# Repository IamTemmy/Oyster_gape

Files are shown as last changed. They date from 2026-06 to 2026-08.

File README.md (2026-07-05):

# Oyster_gape

Non-contact measurement of oyster valve **gape** (how far the shells open and
close) using a Micronas **HAL 2425** Hall-effect sensor on one shell and a small
magnet on the other. As the gap changes, the sensor output changes. This repo
covers the sensor engineering: characterizing and **linearizing** the HAL 2425 so
its output reads linearly in millimetres, then a **three-sensor bench system**
(Board B) that shows live gape on a web dashboard, with a **per-unit tare** so
each unit reports true gape from its own closed baseline.

This is a clean restart. Nothing here is inherited unverified from prior work —
every constant is measured and documented.

---

## Demo

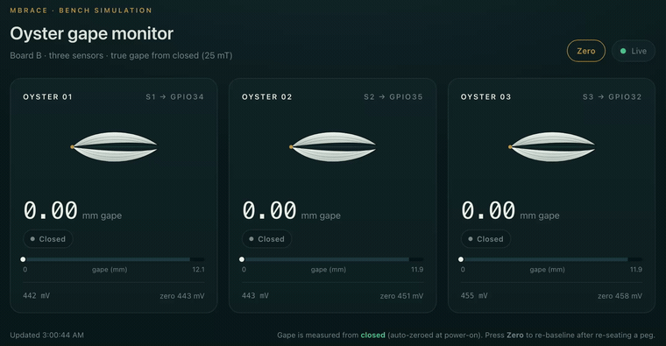
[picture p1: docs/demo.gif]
Oyster gape dashboard demo


Three clothespin "oysters" on Board B's live dashboard — each shell opens in
proportion to the measured gape. Closed reads 0.00 mm (per-unit tare); the
slightest press registers immediately.
**[Watch the full video →](https://github.com/IamTemmy/Oyster_gape/releases/tag/v0.1-bench-demo)**
· more in [`docs/demo.md`](docs/demo.md).

---

## Current stage

**Bench system working — 25 mT + tare (Board B).** The full method is proven on
three clothespin "oysters" (pegs standing in for real animals):

- Sensors characterized and **linearized** (Micronas workflow, Procedure 03),
  first at 12 mT then re-done at **25 mT** (window 8.0–20.0) so the closed peg sits
  on the active ramp instead of in the dead zone.
- **Board B** (ESP32-WROVER) reads all three sensors (S1/S2/S3 → GPIO34/35/32, all
  ADC1) and serves a live **web dashboard** (`firmware/06_board_b_tare`).
- **Per-unit tare:** each unit records its own closed reading as a baseline and
  reports **true gape from closed** — `gape = (mV − baseline) / m`. The intercept
  cancels in that subtraction, so the per-unit mounting offset drops out. This is
  what lets one lab calibration serve many differently-mounted animals.

Per-sensor lines and the full method:
[`data/analysis/deployment_calibration.md`](data/analysis/deployment_calibration.md).
Watch it work: [demo](docs/demo.md).

**Next (deployment):** re-run the same method at the range chosen for real oysters
(see decisions log), add a mounting jig for consistent closed standoff, and
flash-persist the baselines so a tare survives power cycles.

---

## Hardware facts (current rig)

| Item | Value |
|---|---|
| Sensor | Micronas HAL 2425 (16 linearization setpoints) |
| Programmer / software | HAL-APB on COM-port, HAL/HAR 24xy Programming Environment (SW v3.04) |
| Controller | ESP32-WROVER (Freenove) |
| Driver | Geckodrive G251 — **fixed 10 microsteps/full step → 2000 pulses/rev** |
| Motor | 200 full-step |
| Magnet | 3/8" dia × 1/8" thick, N40 neodymium, axially magnetized |

### Pin map

| Signal | ESP32 | Notes |
|---|---|---|
| STEP | GPIO18 | → G251 Terminal 10 |
| DIR  | GPIO19 | → G251 Terminal 9 |
| Sensor analog in | GPIO34 | ADC1_CH6, input-only. **Not** GPIO4 (that is ADC2, WiFi-conflicting) |
| Common ground | GND | shared with G251 Terminal 12 |

### Analog front end (sensor output → ESP32) — DECIDED: ÷1.5, no cap

- **Divider: ÷1.5** (two 10 kΩ in parallel = 5 kΩ on top, one 10 kΩ to ground).
  The Stage 02 2×2 test showed ÷1.5 and ÷2 back-scale to the same true curve
  within 0.3% — ÷1.5 does **not** clip with this magnet/geometry — while ÷1.5
  spans ~1.33× more mV at the pin, giving more ADC resolution. (Re-check if a
  future geometry brings the magnet much closer and raises the output.)
- **No filter cap.** No-cap noise is ~6 mV SD → ~0.45 mV after 200-sample
  averaging — already excellent. On this ÷1.5 setup the cap **reproducibly
  raised** noise (~21 mV SD, confirmed on a clean retest — not a loose
  connection). Cause not pinned down (likely the specific cap interacting with
  the breadboard/ADC), but irrelevant: the cap isn't needed and hurts here, so
  it's dropped. See data/analysis/.
- Decouple the sensor's 5 V supply with 100 nF + ~4.7 µF at its pins
  (output is ratiometric, so supply ripple = error).

---

## Key decisions log

- **Noise:** keep the ESP32 (per advisor); attack noise in firmware via
  oversampling + averaging + settle time, on ADC1. External ADC (e.g. ADS1115)
  held as a fallback only.
- **Analog front end:** **÷1.5 divider, no cap** (Stage 02 2×2 test). ÷1.5
  proven not to clip (back-scales to ÷2 within 0.3%) and gives more resolution;
  cap unneeded because 200-sample averaging drives noise to ~0.5 mV.
- **Magnetic range:** ±3 mT is **blind below ~12 mm** with this magnet (near field
  clips); higher ranges reach smaller gaps. **Bench: ±25 mT** — chosen and
  bench-proven (window 8.0–20.0) because it places the peg's closed gap on the ramp
  without pushing the window start into the steep shoulder (the F:000000 spike).
  **Deployment: likely ±3 mT** for real (larger) oysters — the professor's lean,
  for its longer operating range at larger separations. The *method* is
  range-independent (linearize → mount so closed is on-ramp → tare), so deployment
  re-runs it at the final range once the oyster geometry is known.
  *(Updated 2026-07-05; earlier this read "final choice pending the measured gape window.")*
- **Distance constant:** measured = **0.001 mm/pulse** (1000 pulses/mm,
  2.0 mm/rev), Procedure 01.
- **Output polarity:** sensor output **falls** with increasing gap
  (closed = high mV ~3.6 V, open = low mV). Kept on purpose: it places the
  closed→just-opening transition in the high-signal, high-resolution region —
  the event the research most cares about. A falling curve linearizes exactly
  like a rising one. Deployment caveat: "fully open" and "unpowered / broken
  wire" both read low — rely on the HAL's wire-break detection to disambiguate.
- **Per-sensor calibration:** every sensor is characterized and linearized
  **individually** — setpoint files are NOT shareable between units (intrinsic
  part spread + mounting variation from bent pins + magnet pairing). The process
  is identical each time and the high-level settings (range, output mapping) are
  shared; only the sweep + setpoints + a per-unit 2-point calibration are
  repeated. The 2-point cal is what absorbs mounting-distance variation. A sensor
  must be characterized in (or in a jig replicating) its final mounting geometry.
  Future shortcut to validate empirically: if several sensors' curve *shapes*
  match, share one curve + per-unit 2-point cal only.
- **LOCK is irreversible.** Locking a sensor can never be undone — every
  programming session ends with an explicit LOCK checklist before that button.

---

## Conventions

- One firmware sketch per folder (Arduino requirement), numbered by stage.
- Every stage has a matching `docs/procedures/NN_*.md` with a results table
  filled in from the real run.
- Raw data lands in `data/` with the sketch/run that produced it named in the file.

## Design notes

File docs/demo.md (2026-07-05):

# Demo — bench simulation (25 mT + tare)

Oyster gape dashboard demo

*Board B's live dashboard. Three clothespin "oysters," each with a HAL 2425 sensor
and a magnet on opposing jaws — the clothespin mouth is the shell gape. Each shell
on screen opens in proportion to the measured gape.*

## What the clip shows

- All three start **closed at 0.00 mm** ("Closed").
- Each peg is pressed open — the shell splays and the gape reads live in mm.
- Released back to closed → returns to **0.00 mm**. The per-unit **tare** holds the
  closed baseline, so closed is a true zero, not a fixed guess.

## Setup

- Firmware: [`firmware/06_board_b_tare`](../firmware/06_board_b_tare) on an ESP32-WROVER (Board B).
- Sensors S1/S2/S3 → GPIO34 / GPIO35 / GPIO32 (all ADC1, ÷1.5 front end).
- Linearized at **25 mT**, window **8.0–20.0** (see
  [`data/analysis/deployment_calibration.md`](../data/analysis/deployment_calibration.md)).
- **Per-unit tare:** `gape = (mV − baseline) / m`; the intercept cancels, so each unit
  reports true gape from its own closed baseline — the mechanism that generalizes across
  differently-mounted units.
- Dashboard gauge **auto-scales** to each unit's physical opening range.

## Full video

▶ **[Watch the full demo — Release v0.1-bench-demo](https://github.com/IamTemmy/Oyster_gape/releases/tag/v0.1-bench-demo)**

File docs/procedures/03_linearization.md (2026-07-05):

# Procedure 03 — Per-Range Linearization

**Goal:** for each magnetic range, straighten the sensor's output so it reads
proportional to gap, using the HAL 2425's 16 setpoints, and verify it.

**Sketch:** `firmware/03_linearization/03_linearization.ino` (modes: `cal`, `lin`, `verify`)
**Logger:** `host/sweep_logger.py` (captures the `verify` sweep)

This is the same procedure for all eight ranges — only the **window** changes.

---

## Windows (START / END per range) — verified

These are the **corrected, verified** windows — the value you type: `window START END`.
Each START was pushed past that range's steep shoulder; the initial guesses were too
low and made the linearizer's inverse spike (F:000000, unwritable). Full narrative in
`data/analysis/linearization_log.md`.

| Range | START (mm) | END (mm) | Status |
|---|---|---|---|
| 100 mT | 4.0 | 14.0 | verified (2.6%) |
| 50 mT | 6.0 | 16.0 | verified (1.4%, cleanest) |
| 25 mT | 8.0 | 20.0 | verified (2.0%) — bench build |
| 12 mT | 11.0 | 24.0 | verified (2.3%) |
| 6 mT | 17.0 | 32.0 | verified (2.6%) |
| 3 mT | 20.0 | 38.0 | verified (3.1%) |
| 200 mT | — | — | **IMPRACTICAL** — swing vs gentle-start squeeze |
| 400 mT | — | — | **IMPRACTICAL** — swing too small to calibrate |

START sits just past each range's steep shoulder (further out as sensitivity rises —
a clipped/flat or too-steep span can't be linearized); END sits before the flat tail.
The table gives the **window command**; the *measured* ramp runs a little wider (e.g.
25 mT command 8.0–20.0 → measured ramp ~8.5–20.7, see the range ladder in
`linearization_log.md`). **200 mT and 400 mT do not linearize with this magnet**, so
start the campaign at **100 mT** and work down the table.

## Settings (same for every range)

- **OUT_MIN / OUT_MAX = 10% / 90%** — keeps the signal inside the sensor's
  full-accuracy band (~7–93% VSUP) and leaves headroom for wire-break/clamp
  diagnostics. Don't use 0/100.
- **SCALE_MIN / SCALE_MAX = 1024 / 29696** (the tool defaults) — uses most of
  the internal 0–32767 range.

## Connections — which device owns the OUT line

- **cal / lin:** the **Micronas programmer reads the sensor** → programmer
  connected. (The ESP32 only drives the motor here; it does not read OUT.)
- **verify:** the **ESP32 reads the analog output** → **disconnect the
  programmer** from the OUT line first (the "lines flying" problem).
- STEP/DIR (motor) stay connected the whole time.
- If Micronas comms glitch during cal/lin, also lift the ÷1.5 divider off OUT so
  only the programmer is on it.

---

## Per-range loop

1. **Reset + range** (Sensor Settings): Set Default Values → Magnetic Range =
   target → Write Customer Setup → Power On Reset. (Clears any prior
   linearization so ranges don't stack.)
2. **Set the window in the sketch:** rest the carriage gently on the block →
   `zero` → `window <START> <END>` for this range.
3. **2-Point Calibration** (Micronas tool): enter SCALE_MIN/MAX defaults and
   OUT_MIN/MAX = 10/90 → in the sketch run **`cal`**:
   - it goes to START → click **Calibration Point 1** → press ENTER
   - it goes to END → click **Calibration Point 2** → press ENTER
   - then **Calculate Signal Path** → **Write Signal Path**.
4. **16-point measurement** (Measurement Tool open): in the sketch run **`lin`**:
   - at each of the 16 stops, wait until the magnet has **stopped moving**, click
     **Yes** on the tool's "position reached?" prompt, then press ENTER to advance.
   - when done, the tool **saves the setpoint file** itself.
5. **Linearize + write setpoints** (Linearization Tool): Load Meas. File →
   **Linearize with Extrapolation UNCHECKED** (clamps the output outside the window)
   → **inspect the green Transfer Curve before writing** — a smooth bow is good, a
   small kink is usually fine, but a **big spike (hundreds–thousands of %FS) means DO
   NOT write**: the write fails with `error during programming F:000000`. That spike
   means the window START sits on the curve's steep shoulder — move START further out
   and redo from step 2. When the green curve is clean → **Write Setpoints**.
6. **Verify:** disconnect the programmer from OUT. In the logger set
   `:range <range>mT_linearized`, then in the sketch run **`verify`**. The logger
   saves `charac_<range>mT_linearized_run1.csv` + `.png`.

**The green Transfer Curve is the go/no-go; the `verify` sweep is the final arbiter.**

**A good verify looks like:** flat clamp (10%) → straight diagonal ramp across
the window → flat clamp (90%). The straight ramp is the proof. Overlay it on the
raw `charac_<range>mT` curve for the before/after figure.

---

## Sketch command reference

```
zero              set datum at current position (do this on the block)
window <a> <b>    set window, e.g.  window 1.0 10.0
cal               visit START then END (ENTER to advance, q to abort)
lin               walk 16 even stops START->END (ENTER each, q to abort)
verify            100 mm sweep, streamed to the logger
<integer>         jog pulses (1000 = 1 mm, + = away from sensor)
pos / help
```

One command at a time; wait for each reply (avoids the merged-line problem).

## Records to keep per range

Sensor ID/channel, range, window START/END, OUT_MIN/MAX, the saved setpoint
file, and the `verify` CSV/PNG. These are the per-unit calibration identity.

## Notes

- Output falls with gap (our polarity), so the linearized ramp will also be a
  clean monotonic line — direction doesn't matter to the linearizer.
- `cal`, `lin`, `verify` all return to the datum (block) when finished, so you
  don't reposition between steps. Re-`zero` on the block if you suspect drift.

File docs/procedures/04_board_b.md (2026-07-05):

# Procedure 04 — Board B: live readout, dashboard, and tare

**Goal:** read the linearized sensors on a second ESP32 (Board B) and report
**true gape** — the shell opening from closed — on a serial readout and a live web
dashboard.

**Sketches (Board B, one folder each):**
- `firmware/04_board_b_readout/` — 3-sensor serial readout (bench debug)
- `firmware/05_board_b_dashboard/` — WiFi web dashboard (absolute mm)
- `firmware/06_board_b_tare/` — **current**: 25 mT + tare, reports true gape

**Calibration source:** `data/analysis/deployment_calibration.md` (per-sensor `m`,
`b`, ramp, clamp floors).

---

## Hardware (Board B — no motor)

| Signal | ESP32 | Notes |
|---|---|---|
| S1 in | GPIO34 | ADC1_CH6 |
| S2 in | GPIO35 | ADC1_CH7 |
| S3 in | GPIO32 | ADC1_CH4 |

- **All three on ADC1.** ADC2 shares hardware with the WiFi radio, so ADC2 reads
  fail once the dashboard's WiFi is up. ADC1 always works.
- One **÷1.5 divider per sensor** (2×10 kΩ parallel on signal + 1×10 kΩ to GND);
  do not share divider legs. Same front end as the rig.
- USB-powered (Phase 1). Battery/power is Phase 2 — deliberately not built in.

## Which sketch to flash

- **06 is the current build** — flash it for the demo and for true-gape readings.
- 04 (serial only) and 05 (dashboard, absolute mm) are kept as references / bench
  debug; 06 supersedes both.

## WiFi (05 / 06)

- Credentials + mode live in `secrets.h` (**gitignored**). Copy
  `secrets.example.h` → `secrets.h` in the sketch folder and fill it in.
- `NET_MODE`: `NET_AP` (Board B makes its own network → `http://192.168.4.1`) or
  `NET_STA` (join existing WiFi → IP printed on serial at boot). AP is the more
  reliable demo path; some institutional networks isolate clients and block the
  laptop from reaching Board B even when both are "connected."

---

## Before tare — the two gate checks

The tare only works if closed sits **on the ramp**. After mounting, read the raw
mV (serial `read`, or the dashboard footer) and confirm both:

1. **Closed peg on the ramp** — a mid-ramp mV, not the ~300 mV floor (CLAMP-LO).
2. **A realistic full-open still on the ramp** — under the ~3130 mV ceiling, not
   CLAMP-HI / "above window".

If closed clamps low, the window is too high for this mounting → re-linearize lower
(Procedure 03) or increase the mounting standoff. If full-open clamps high, the
opening range exceeds the window → widen it or drop to a lower range. (For the 25 mT
peg build these both passed: closed ~450 mV / ~8.5 mm, full-open ~2510 mV / ~17.9 mm.)

## Tare workflow (06)

    gape = (mV − baseline) / m

The intercept `b` cancels in that subtraction, so the per-unit mounting offset drops
out — every unit zeroes to itself and reads 0.00 mm closed.

- **Auto-capture at boot:** ~1.5 s after power-on the firmware captures each
  sensor's closed reading as its baseline. **Hold the pegs CLOSED through boot.**
- **On-ramp gate:** an off-ramp / clamped reading is **refused**, not zeroed to
  junk (shows "No baseline"). Close the peg and re-zero.
- **Re-baseline anytime:** serial `zero`, or the dashboard **Zero** button — needed
  after re-seating a peg or separating the magnet/sensor halves.
- **"Closed" band:** within ±0.05 mm of baseline reads as closed (≈ the noise
  floor), so closed holds steady; any real press registers immediately.
- **Gauge auto-scales** to each unit's physical max opening (`rampHi − baseline`) —
  no fixed full-scale constant.

---

## Sketch command reference (serial, 115200)

```
zero    re-capture the closed baseline (hold pegs closed first)   [06]
read    one-shot verbose read — absolute mm + gape                [04 / 06]
help    menu
```

The live readout is the web dashboard; serial is for setup / debug.

## Records to keep

Per unit: sensor ID → channel, the 25 mT `(m, b)` line used, the closed baseline mV
captured at install, and a caliper spot-check of gape at one open position.

## Notes

- Baselines live in RAM (re-captured each boot / on `zero`). **Deployment TODO:**
  persist to flash so a tare survives a power cycle.
- The tare removes **offset**, not **slope** — the magnet used at linearization must
  match the deployed magnet, or gape is scaled wrong.
- Hinge-arc error (the peg/oyster opens on an arc, not the rig's straight line) is
  taken as **minimal** per the professor; the tare does not correct it. Revisit if an
  animal opens much wider. See `data/analysis/deployment_calibration.md`.

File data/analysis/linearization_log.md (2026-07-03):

# Stage 03 — Linearization results log (per range)

Magnet: 3/8" x 1/8" N40 (fixed). Front end: ÷1.5, no cap. OUT_MIN/MAX = 10/90.

| Range | Window (mm) | Cal pt1 | Cal pt2 | Result |
|---|---|---|---|---|
| 400 mT | 1.0–10.0 | 3004 | 408 | REJECTED — "small range between calibration points" |
| 400 mT | 0.5–25.0 | 3444 | 64 | REJECTED — swing too small even widened. **400 mT not linearizable with this magnet.** |

## Notes
- 400 mT is the least sensitive range; its internal signal swing over the usable
  span is too small for the 2-point calibration to anchor. The tool itself flags
  it and suggests lowering the magnetic range — consistent with the Stage 02
  sensitivity analysis (400 mT had the smallest swing of all eight).
- Expectation: 200 mT likely the same; the sensitive ranges (50 mT and down) are
  the real candidates.

| 200 mT | 1.0–10.0 | 5940 | 808 | Calibrated OK, but linearization transfer spiked (>1000% FS) — unwritable (F:000000). |
| 200 mT | 4.0–14.0 | 2704 | 456 | REJECTED — pushing start out to tame the spike drops swing below calibration minimum. |
| 100 mT | 1.0–10.0 | 11932 | 1660 | Calibrated OK, but transfer spiked (~700% FS) — unwritable. Retesting with pushed-out start. |

## Finding (400 + 200 mT)
The two least-sensitive *non-clipping* ranges fail to linearize with this magnet,
for two linked reasons:
- **Swing too small** for the 2-point calibration (400 mT outright; 200 mT once
  the window is pushed out).
- **Steep first segment** (curve is steepest right at the block on non-clipping
  ranges) makes the linearizer's inverse spike (>1000% FS) → setpoints unwritable.
There is no window that gives both enough swing AND a gentle-enough start.
=> 400 mT and 200 mT are documented as IMPRACTICAL with the current magnet.
Next: confirm whether 100 mT (more swing) escapes the squeeze with a pushed-out start.

| 100 mT | 4.0–14.0 | 5404 | 916 | **SUCCESS** — smooth transfer, written, verified. Ramp straight to 2.6% (max 75 mV dev on 2900 mV ramp), slope ~260 mV/mm. |

## Method confirmed
The fix for non-clipping ranges: **start the window past the steep first segment**
(4 mm for 100 mT). 1 mm spiked (unwritable); 4 mm gave a clean flat–ramp–flat
verified at 2.6% linearity. 100 mT is the first fully linearized + verified range.

| 50 mT | 3.0–13.0 | 13636 | 2076 | Transfer spiked — start still too steep. |
| 50 mT | 6.0–16.0 | (recal) | | **SUCCESS** — smooth transfer, written, verified. Ramp straight to **1.4%** (max 39 mV dev), slope 258 mV/mm. Cleanest range so far; front-runner. |

## Linearization-safe window starts (corrected, per range)
Each range needs its window START pushed past its steep shoulder (further out as
sensitivity rises), or the linearizer's inverse spikes and setpoints won't write:
- 100 mT -> start 4.0 mm  (verified, 2.6%)
- 50 mT  -> start 6.0 mm  (verified, 1.4%)
- 25 mT  -> testing ~8.0 mm
(200/400 mT impractical: can't get swing + gentle start simultaneously.)

| 25 mT | 8.0–20.0 | (ok) | | **SUCCESS** — verified, ramp straight to 2.0%, slope 217 mV/mm, 8.5–20.7 mm. Wider window than 50mT. |

| 12 mT | 11.0–24.0 | (ok) | | **SUCCESS** — verified, see straightness in session. Window 11–26 mm. |

| 6 mT | 17.0–32.0 | (ok) | | **SUCCESS** — verified. Window 17–37 mm; widest span yet before 3mT. |

| 3 mT | 20.0–44.0 | (ok) | | First try bent at top (5.8%) — END reached the flat zone. Re-run accepted at 3.1%. |

---

# STAGE 03 — FINAL RESULTS (6 ranges linearized + verified)

| Range | Window start→end (mm) | Width (mm) | Slope (mV/mm) | Linearity (max dev) |
|---:|:---:|:---:|:---:|:---:|
| 3 mT | 21.8–43.7 | 21.9 | 115 | 3.1% |
| 6 mT | 18.2–36.4 | 18.2 | 140 | 2.6% |
| 12 mT  | 11.4–25.2 | 13.8 | 187 | 2.3% |
| 25 mT  | 8.5–20.7  | 12.2 | 217 | 2.0% |
| 50 mT  | 6.4–16.4  | 10.0 | 258 | 1.4% (cleanest) |
| 100 mT | 4.1–14.2  | 10.1 | 260 | 2.6% |
| 200 mT | — | — | — | IMPRACTICAL (swing vs gentle-start squeeze) |
| 400 mT | — | — | — | IMPRACTICAL (swing too small to calibrate) |

## Key findings
1. **Six usable linearized ranges (3–100 mT)**, each a straight gap-vs-output
   ramp, all within 1.4–3.1% linearity. Together they form a "range ladder":
   pick the range whose ramp covers a given oyster's gape window.
2. **Window rule:** each range's window must START past its steep shoulder
   (further out as the range gets more sensitive) and END before its flat tail —
   else the linearizer's inverse spikes (unwritable) or the ramp bends.
3. **Magnet reach limit ≈ 38 mm.** Going to the most sensitive range (3 mT) did
   NOT extend usable reach much beyond 6 mT — the field flattens by ~38 mm
   regardless of range. The largest gapes would need a stronger magnet.
4. **200/400 mT impractical** with this magnet: too little signal swing to both
   calibrate and linearize.
5. Measurement quality: more-sensitive ranges trade slope (resolution) for reach.
   50 mT is the cleanest/highest-resolution general-purpose choice.

## Open / next
- Deployment: pick range per oyster from its actual gape window (closed+open mm).
- Set Clamp-Low/High band + wire-break detection (currently 0/100).

---

# Experiment: magnetic range acts UPSTREAM of the signal path (CFX evidence)

**Question (raised by colleague):** can the stored signal path be tweaked to move a
range's ramp along the *distance* axis — e.g., make 3 mT read near the block like
100 mT does?

**Method:** magnet held FIXED at distance 0 (closest to block). Changed ONLY the
Magnetic Range dropdown; clicked Read All Registers each time. No recalibration,
no Load Signal Path.

**Observation (same magnet, same position):**

| Range  | CFX (raw sensed) | OUT[%FS] | Signal-path registers |
|---:|:---:|:---:|:---:|
| 100 mT | 16887 (~half scale) | 7.14 | unchanged |
| 50 mT  | 32767 (RAILED) | 7.14 | unchanged |
| 3 mT | 32767 (RAILED) | 7.14 | unchanged |

- Signal-path coefficients (TCCG / SCALE / OUT / clamps) did NOT change with range.
- Only RAM (live pipeline) values changed. **CFX is the tell.**

**Conclusion:**
- Magnetic range sets front-end sensitivity BEFORE the signal path. At a fixed
  strong-field position the sensitive ranges (3/50 mT) rail the raw sensed value
  (CFX = 32767 = full scale); the insensitive range (100 mT) stays ~half scale.
- A railed CFX cannot be recovered by any downstream signal-path math → output
  pinned (7.14 %FS) regardless of coefficients.
- Therefore the signal path shapes the ramp VERTICALLY (level / slope / straightness)
  but CANNOT move it along the distance axis. Ramp *position* is set by where CFX
  comes off the rail = the magnetic range's job. The range ladder is the
  horizontal-position mechanism; the signal path is the shaping mechanism.
- CFX is a live READ-ONLY pipeline value (Read RAM); it is NOT a writable setting.
  It re-measures the real field every read, so it can't be "set" to another value.
- Note: SETPT_OUT = 0 in all three shots → no linearization setpoints active in the
  currently-loaded recipe (a bare/leftover calibration, not one of the 6 verified).

**Efficiency spin-off (deployment range selection):**
Park the magnet at the oyster's CLOSED-gap distance (strongest field) and Read CFX
per range. Any range showing CFX = 32767 is railed at closed → disqualified without
a full sweep. Filter losers first, then linearize only the survivor(s).

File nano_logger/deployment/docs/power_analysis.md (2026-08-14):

# Nano logger — power analysis summary

Method: Agilent E3631A bench supply @ ~5.00 V into the Nano 5V pin, USB unplugged
(supply's current readout = total draw). DMM used for spot cross-checks. Board is
an unaltered clone Nano unless a row says a component was removed. "Asleep" =
LowPower.powerDown deep sleep.

## Build-up: current vs what's connected (CPU asleep unless noted)

| State | Configuration | Current | Delta (this item) | Notes |
|---|---|---:|---:|---|
| 0  | Bare Nano, empty sketch (CPU awake) | 21 mA | — | unaltered board |
| 1  | Bare Nano, deep-sleep sketch (asleep) | 10 mA | -11 mA | CPU active ~11 mA; 10 mA = parasitic floor |
| 2  | + RTC module (DS3231) | 14 mA | +4 mA  | mostly the module's power LED |
| 3  | + SD module (card in) | 16 mA | +2 mA  | no LED on module — efficient |
| 4  | + 3 Hall sensors, UNGATED (VDD->5V) | 39 mA | +23 mA | ~7.5 mA per sensor (measured over 4) |
| 5  | 3 sensors GATED (VDD->GPIO D4/D5/D6) | 16 mA | -23 mA | sensors on ~3% duty; biggest single win |

## Strip-down: removing parasitics (bare board, asleep; baseline 10 mA)

| Strip | Action | Before | After | Saved | Result |
|---|---|---:|---:|---:|---|
| #1 | Remove RTC module power LED (D1) | 14 mA | 11 mA | ~3 mA | RTC still keeps time |
| #2 | Remove Nano onboard PWR LED | 10 mA |  7 mA | ~3 mA | board still runs |
| #3 | Cut/lift CH340 VCC (pin 16) |  7 mA |  7 mA | ~0 mA | no change — chip back-feeds via signal pins |
| #3b| Also lift CH340 TXD+RXD (pins 2,3) |  7 mA |  7 mA | ~0 mA | LEDs off but current unchanged |
| #3c| Remove entire CH340 (other board)  |  7 mA |  7 mA | ~0 mA | confirms CH340 is NOT a meaningful draw here |
| #4 | Remove AMS1117 voltage regulator |  7 mA |  2 mA | ~5 mA | THE real culprit — bare-board floor now 2 mA |

## Final node (working, USB-programmable board: LEDs + regulator out, CH340 kept)

| Build step | Current | Delta | Notes |
|---|---:|---:|---|
| Stripped bare board | 2 mA | — | LEDs + regulator removed |
| + RTC (LED-stripped) | 3 mA | +1 | just chip + pull-ups |
| + SD (card in) | 5 mA | +2 | no LED, efficient |
| + 3 sensors GATED | 6 mA | +1 | avg; spikes 11-13 mA on 3 ms read |

Journey: **51 mA (original, awake, ungated)  ->  6 mA (stripped + gated, still uploads over USB)**.
Six-sensor projection: 5 + 6*~0.4 = ~7-8 mA average. ~7-8x improvement.
Two big wins: sensor gating (~44 mA on 6) and regulator removal (~5 mA). CH340
removal is pointless (0 mA, back-feeds). Deployment: bare ATmega328P starts here
with no surgery.

## Key findings
- Sensors, always-on, are the LARGEST load (~7.5 mA each; ~45 mA for 6). GPIO-gating
  is the #1 win — cut 3 sensors from +23 mA to ~0.
- Indicator LEDs are pure waste: RTC LED ~3 mA + Nano PWR LED ~3 mA = ~6 mA reclaimed.
- CH340 USB chip draws ~nothing on these clones — removed 3 ways, 0 mA change. It also
  BACK-FEEDS through its signal pins when VCC is cut (2.37 V measured on the lifted VCC
  pin), so it can't be cleanly isolated on a clone. Lesson: "off" isn't off if signal
  lines still feed a chip.
- Remaining ~7 mA floor is NOT the CH340. Leading suspects: AMS1117 regulator quiescent
  draw and/or the ATmega's real deep-sleep current on this clone. Next: measure
  regulator; verify true sleep depth (board warmth / confirm sketch).

## Six-sensor deployment projection (asleep)
- Ungated: 16 (RTC+SD) + 6*7.5 = ~61 mA
- Gated:   ~17 mA  => gating saves ~44 mA on a full node; LED stripping adds ~6 mA.

## Deployment implication
Clean sub-milliamp current can't be reached by stripping a clone Nano (CH340 is
entangled and back-feeds). This is bench evidence FOR building deployment nodes on a
bare ATmega328P (Path B) rather than a modified clone.

---
# Detailed measurement log (chronological notes)

# Nano logger — component-level power analysis

Method: powered from Agilent E3631A (+6V output @ ~5.00 V) into the Nano 5V pin,
USB unplugged (both connected gives a false low/mixed reading — verified: USB+supply
read 15 mA vs 10 mA supply-only). E3631A current readout = primary; handheld DMM in
series = cross-check. Board is an UNALTERED clone Nano (CH340, power LED, regulator
all intact) unless a state says otherwise. Datasheet predictions listed for comparison.

Predictions (5 V, 16 MHz): ATmega328P active ~8-12 mA, deep-sleep ~1 uA (chip);
board parasitics (CH340+LED+reg) ~10-20 mA; DS3231 module ~1-3 mA; SD idle ~few mA;
HAL2425 ~6-10 mA each (to be pinned down by per-sensor delta).

## State 0 — Bare Nano, empty sketch (CPU awake)
Sketch: empty setup()/loop().
E3631A: 21 mA   DMM: 18.3 mA (verify; ~2-3 mA offset expected between instruments)
Note: unaltered board, LED + CH340 intact. Lands in predicted 15-25 mA range.

## State 1 — Bare Nano, deep-sleep sketch (CPU asleep)
Sketch: LowPower.powerDown(SLEEP_8S, ADC_OFF, BOD_OFF) in loop.
E3631A: 10 mA, rock steady.
Observation: no visible spike at the 8 s watchdog wake — the wake is only a few ms,
far too brief/rare for the supply's slow display to show. Confirms CPU sleeps ~99.97%
of the time. (Catching the blip would need a scope or fast current profiler.)

### Interpretation (States 0-1)
- CPU active draw = 21 - 10 = ~11 mA  (matches ~8-12 mA datasheet prediction).
- Parasitic floor = 10 mA (CH340 + LED + regulator; do not sleep with the CPU).
- => 10 mA is the FLOOR this board cannot go below without physically stripping
  parasitics. Sets the ceiling on what the strip-down stage can save.

## State 2 — +RTC module (DS3231), asleep and awake
Wiring: SDA=A4 SCL=A5 VCC=5V GND=GND (no SQW needed — not waking from it here).
Asleep: 14 mA (+4 from floor).  Awake: 25 mA (+4).
Observation: DS3231 module LED lit. Chip itself is ~0.1-0.2 mA, so the ~4 mA
delta is mostly the MODULE's power LED + pull-ups -> a strippable parasitic.

## State 3 — +SD module (card inserted), asleep and awake
Wiring: CS=D10 MOSI=D11 MISO=D12 SCK=D13 VCC=5V GND=GND.
Asleep: 16 mA (+2 from State 2).  Awake: 27 mA (+2).
Observation: NO LED on the SD module -> the +2 mA is honest regulator + card
idle, not a vanity LED. SD is one of the efficient parts of the stack.
Note: SD WRITE draws far more (tens of mA in ms bursts) but is invisible to the
E3631A's slow display and averages down over the write duty cycle. The write
spike belongs in the profiler-based battery estimate, not this steady-state set.

## State 4 — +Hall sensors, UNGATED (VDD -> 5V rail, always on), asleep
Baseline (RTC+SD, asleep) = 16 mA. VDD->5V, GND->GND, OUT->A0/A1/A2(/A3).
  +sensor1: 24 mA  (delta 8)
  +sensor2: 31 mA  (delta 7)
  +sensor3: 39 mA  (delta 8)
  +sensor4: 46 mA  (delta 7)  [added as arithmetic check]
=> Per HAL2425 ~7-8 mA (avg ~7.5), tightly consistent, matches ~6-10 mA datasheet.

Six-sensor extrapolation (ungated): 16 + 6*7.5 = ~61 mA asleep.
KEY FINDING: always-on sensors are the LARGEST load in the system (~45 mA for 6),
bigger than the CPU (~11) or all parasitics (~10) combined. This is the #1 target.
Gating sensors (~3 ms on per 100 ms = ~3% duty) drops their averaged draw from
~45 mA to ~1.4 mA. Biggest single win available -> validates GPIO-gating design.

## State 5 — Sensors GATED (VDD -> GPIO D4/D5/D6, direct-GPIO), asleep
Sketch: gated_sensor_test.ino — power sensors ON, settle 3 ms, read, power OFF,
deep-sleep 120 ms. Sensors powered ~3% duty cycle.
Wiring: S1 VDD=D4/OUT=A0, S2 VDD=D5/OUT=A1, S3 VDD=D6/OUT=A2, all GND=GND.

Reading: steady 16 mA, with brief twitches to 20-24 mA.
Interpretation:
  - 16 mA = time-average (sensors mostly OFF/asleep). Matches RTC+SD floor: the
    3 sensors' ~23 mA of always-on draw collapsed to ~0.7 mA averaged.
  - 20-24 mA twitches = the ~3 ms sensor-ON pulses caught on display refresh;
    each ~7-8 mA/sensor. Their presence CONFIRMS the gating is powering sensors
    during reads (flat 16 mA with no twitch would mean sensors never powered).

Comparison (3 sensors, asleep): UNGATED 39 mA -> GATED 16 mA.
  => ~23 mA reclaimed (3 sensors). Six-sensor projection: ~61 mA -> ~17 mA,
     ~44 mA saved by gating alone. Largest single win in the analysis.
Method note: gated draw is a ~3% duty pulse, invisible as a steady value on the
E3631A; the 16 mA average is the battery-relevant number. Exact per-pulse energy
needs a profiler, for the final battery estimate.

Verification: the periodic 20-24 mA twitch is itself proof the gate opens/closes;
a separate "comment out the power-OFF line -> jumps to ~39 mA" test also available.

## State 6 — STRIP #1: remove RTC module power LED (D1), asleep
Before (RTC + LED, sleeping): 14 mA.
Action: removed D1 (green power LED near "POWER" silkscreen) from HW-084 DS3231
module. Left everything else (pull-ups R1-4/P2-4, C1/C2, coin-cell diode, EEPROM,
crystal) intact — one component per measurement.
After (RTC, LED removed, sleeping): 11 mA.
=> LED cost = ~3 mA of pure waste, removed. RTC module now adds only ~1 mA over
   the 10 mA bare-board floor (~= DS3231 chip 0.2 mA + pull-ups). As predicted.
Function check: flashed 01_rtc_test after removal — RTC boots, ticks 1 s/line,
anchors to real time on 's' (time_valid 0->1). No functional damage from strip.

### Sneak-current observations (IGNORE for budget, but instructive)
While probing with the power path half-broken:
  - Nano VCC removed, RTC still wired via I2C: read 3 mA.
  - Only GND to Nano, RTC wired: read 7 mA.
These are NOT any component's real draw. They are phantom/back-feed currents:
with the Nano's proper VCC removed, current sneaks INTO the Nano through the
SDA/SCL signal lines + I2C pull-ups and the chip's input-protection diodes.
Artifact of measuring with a broken power path; vanishes when powered normally.
DEPLOYMENT LESSON: a "powered-off" chip can still be back-fed through its signal
pins -> when we power-gate components, ensure signal lines don't keep them
partially alive (e.g. a gated sensor drawing through its OUT line). "Off" must
be truly off.

Ledger (asleep): floor 10 | +RTC(LED-stripped) 11 | (was +RTC intact 14).

## State 7 — STRIP #2: remove Nano onboard PWR LED, asleep
Before (bare board, sleeping): 10 mA.
Action: removed the "PWR" LED (2nd of 4 in the L/PWR/TX/RX row, above "PWR"
silkscreen). Left L (pin13/SCK), TX, RX untouched — TX/RX only draw during USB,
so they're already dark in deployment.
After (bare board, sleeping): 7 mA.
=> PWR LED cost = ~3 mA (clone-board LED running bright). Board still uploads/runs.

Ledger (bare board, asleep):
  10 mA original floor -> 7 mA after removing PWR LED.
Remaining 7 mA = CH340 USB-serial chip (~5 mA, the big one) + regulator quiescent.
Two LEDs stripped total (RTC ~3mA + Nano PWR ~3mA) = ~6mA of indicator-LED waste
reclaimed. Next target: CH340 (biggest single parasitic, sacrificial strip).

## Strip #4 — Remove AMS1117 voltage regulator (asleep)
Before (LEDs stripped, CH340 isolated): 7 mA.
After removing the AMS1117 regulator: 2 mA.
=> Regulator quiescent draw = ~5 mA. THE single biggest remaining parasitic
   (supervisor correctly flagged it). Powered via 5V pin, so the regulator was
   drawing bias/quiescent current with no useful function -> removed.

Bare-board sleeping floor is now ~2 mA (was 10 mA original). This is essentially
the ATmega's real deep-sleep current + residual passives — the practical floor
for this board.

### Updated finding: where the original 10 mA floor actually went
  - CH340 USB chip:      ~0 mA  (surprise — predicted ~5 mA; back-feeds, not a draw)
  - Nano PWR LED:        ~3 mA
  - AMS1117 regulator:   ~5 mA  (the real culprit)
  - ATmega deep sleep + passives: ~2 mA (remaining floor)

### Full-node projection (gated + stripped, asleep)
  stripped bare board ~2 + RTC(LED-stripped) ~1 + SD ~2 + 6 sensors gated ~1.4
  = ~6-7 mA average  (vs 51 mA original unoptimized = ~8x improvement)

This is the number that makes a month+ deployment realistic on a modest battery.

## FINAL — Full stripped + gated node (working, reprogrammable board)
Board: fresh Nano, LEDs + regulator removed, CH340 KEPT (draws ~0, preserves USB).
Built the system up on this working board, measuring each addition (asleep):
  stripped bare board:      2 mA
  + RTC (LED-stripped):     3 mA  (+1)
  + SD (card in):           5 mA  (+2)
  + 3 sensors GATED:        6 mA  (+1 averaged)   <-- FINAL

Gated-sensor reading: settles 6 mA, spikes 11-13 mA on the 3 ms read window
(spikes confirm sensors ARE powered during reads = gating cycling correctly).
First 3 s shows ~19-21 mA = boot delay(3000) awake window; ignored.

Wiring lesson: initial 25 mA reading was a wiring swap — signals were on
D4/D5/D6 and VDD was still on the 5V rail, so sensors ran 24/7. Fixed:
VDD -> D4/D5/D6 (gated power), OUT -> A0/A1/A2 (signal). Then gating worked.

### Full journey
  51 mA  original unaltered board, awake, 3 sensors ungated
   2 mA  stripped bare board (LEDs + regulator removed)
   6 mA  stripped + RTC + SD + 3 sensors gated (working, USB-programmable board)

Six-sensor projection: 5 (RTC+SD) + 6*~0.4 gated ~= 7-8 mA average.
=> ~7-8x better than the 51 mA start, on a board that still uploads over USB.
Makes a month+ deployment realistic on a modest battery.

### Deployment takeaway
Best prototype config = strip LEDs + regulator, KEEP CH340 (0 mA cost, keeps USB),
gate sensors via GPIO (one per pin). For the real build, a bare ATmega328P starts
here without any surgery. Sensor gating + regulator removal are the two big wins;
CH340 removal is pointless (0 mA, and it back-feeds).

## MEASURED — Full SIX-sensor gated node (not projected)
Board: working stripped board (LEDs + regulator out, CH340 kept), all 6 sensors
gated on individual GPIO pins.
Wiring: S1 D4/A0, S2 D5/A1, S3 D6/A2, S4 D7/A3, S5 D8/A6, S6 D9/A7; all GND=GND.
Sketch: gated_sensor_test_6ch.ino (delay(3000) boot window for reprogramming).

Reading: settles 6 mA; spikes 19-21 mA on the 3 ms read (all 6 sensors on).
=> 6 sensors gated add essentially nothing over 3 sensors gated (both ~6 mA),
   because sensors are only powered ~3% of the time. This REPLACES the earlier
   ~7-8 mA six-sensor projection with a measured 6 mA.

### Final measured result
  51 mA  original unaltered board, awake, 3 sensors ungated
 ~61 mA  six sensors UNGATED (projected)
   6 mA  six sensors STRIPPED + GATED (MEASURED, working USB-programmable board)
  => ~9-10x improvement. This is the deployment node's real average current.

Note: brief per-read spikes (~45 mA instantaneous for 6 sensors, ~20 mA as seen
on the slow display) and SD-write spikes are NOT captured by the E3631A and will
be folded into the battery estimate via a current profiler (PPK2/Otii).

Upload troubleshooting note: a Mac CH340 driver conflict (two competing drivers)
caused "Device not configured" / port-drop upload failures. Uploading from a
different PC worked on all boards. Fix pending: clean up the Mac CH340 driver.

## Deployment firmware — Timer1 10 Hz interrupt (per supervisor)
Sketch: firmware/nano_logger_deploy_10hz/nano_logger_deploy_10hz.ino
Architecture (as specified): hardware Timer1 compare-match interrupt fires every
100 ms (exactly 10 Hz); the interrupt wakes the CPU from IDLE sleep; on wake it
gates the 6 sensors, reads, timestamps (RTC), writes a CSV row to SD, sleeps.

Verified from logged data (LOG0002/LOG0003):
  - Timing: ms-step = 100 for the large majority of rows (LOG0003: 2009 rows @100,
    915 @101, 797 @99) -> clean 10 Hz, +/-1 ms jitter. Confirms Timer1 timing.
  - time_valid works: LOG0002 anchored (2026 timestamps, time_valid=1 after 's');
    LOG0001/0003 unanchored (year-2000 placeholder, time_valid=0).
  - All 6 sensor channels populated with sensible values.

Power: ~9 mA settled at 10 Hz on the test board (spikes ~20-30 mA on the 3 ms
6-sensor read). This is the exact-10Hz cost:
  - IDLE sleep (~9 mA @ 10 Hz) vs deep-sleep watchdog (~6 mA @ 8 Hz): ~3 mA is
    the price of exact 100 ms timing. You CANNOT have exact 10 Hz AND deepest
    sleep — the hardware timer that gives exact timing must keep its clock
    running, which is what deep power-down shuts off.
  - L LED: removing it changed the reading ~0 mA. It only flickers briefly on SD
    writes, so its time-averaged draw is negligible (earlier ~1-3 mA estimate was
    wrong — measurement corrected it).

Why the watchdog can't do 10 Hz: its intervals are fixed steps (16/32/64/125/250
/500 ms...); nearest to 100 ms is 125 ms = 8 Hz. No exact 100 ms step exists.

Open decision (supervisor): drop the RTC? It costs only ~1 mA, so removing it
barely saves power. The real tradeoff is TIME: without the RTC every sample has
only millis() (time-since-boot), not wall-clock time. Absolute time can still be
reconstructed IF each node's exact deploy moment is recorded (millis + known boot
time -> absolute). Needed if correlating gape with tide / day-night. Decision is
"do we track deploy-time manually across ~16 nodes, or let each node stamp its
own time for ~1 mA" — not a power question.

## DAQ6510 precision measurement — true average current (10 Hz deployment sketch)
Instrument: Keithley DAQ6510 6.5-digit DMM, DC current, front AMPS terminal, in
series with the board's 5V line. E3631A at 5 V. Sketch: nano_logger_deploy_10hz.
Capture: 100,000 readings over 50.2 min (~33 readings/s), buffer saved to USB.
Data: data/daq_current/daq_10hz_run1.csv

RESULT — true time-weighted average current: 8.40 mA
  (this is the battery-life number; captures spikes the E3631A could not show)

Distribution is BIMODAL:
  - 70% of time at ~7.34 mA  (between reads / IDLE sleep)
  - 30% of time at ~10.87 mA (CPU awake: read + timestamp + SD write)
  - min 7.27 mA, max 23.68 mA (6-sensor read peak), mean 8.40, std 1.64 mA
Eyeballing the display read ~7 mA (the more common low value); the DAQ's weighted
mean of 8.40 mA is higher because the 30% spent at ~10.9 mA pulls it up. This is
exactly why the precision DAQ measurement was needed.

Battery life at 8.40 mA:
  3500 mAh  -> ~17 days      3x3500 (10,500 mAh) -> ~52 days (month+ target met)
Conclusion: exact 10 Hz (IDLE sleep) costs ~8.4 mA -> one cell ~17 days, so a
month+ needs a multi-cell pack (planned: 3 cells) OR a lower sample rate.
Plot: docs/daq_current_analysis.png

## DAQ6510 measurement campaign + power-integrity investigation

### Goal
Use the Keithley DAQ6510 (6.5-digit DMM, in series on the 5V line) to get a
precise, spike-inclusive TIME-AVERAGED current for the 10 Hz deployment sketch,
better than the E3631A's coarse readout.

### Run 1 (clean) — the trustworthy number
DAQ in series, no USB, no capacitor. 100k readings / 50 min.
  TRUE MEAN = 8.40 mA. Bimodal: ~70% at ~7.34 mA (between reads), ~30% at
  ~10.87 mA (CPU awake: read+timestamp+SD write). Max 23.7 mA (6-sensor read).
This is the accurate battery number for the 10 Hz IDLE-sleep deployment sketch.
Battery life: 3500 mAh -> ~17 days; 3x3500 (10,500 mAh) -> ~52 days (meets month+).

### Runs 2/3 (faulty) — intermittent high-current / dropouts
Repeat runs gave 30.9 mA and 16.7 mA with sustained ~30-60 mA plateaus and
0 mA dropouts. Investigated thoroughly:
  - NOT firmware: the board's own SD logs stayed clean 10 Hz (73k rows, 0
    overruns, max gap ~128 ms) THROUGH the faulty DAQ captures. The board ran
    perfectly; only the DAQ current trace showed dropouts.
  - NOT SD-card fill: a freshly cleared card still showed the fault.
  - NOT sensor inrush brownout alone: adding a 100 uF cap did not fully fix it.
  - Hundreds of tiny empty LOG####.CSV files earlier were from repeated
    reboots in one bad session, not normal operation.

### Root cause — the DAQ series path, not the board
Decisive test: powering the board from the E3631A ALONE (no DAQ in series, no
cap) ran flawlessly — LOG: 21,700 rows, clean 10.00 Hz, 0 overruns, 36 min.
=> The board + firmware + E3631A are rock-solid. The instability was introduced
   by the DAQ's series measurement path (its internal shunt + clip contacts +
   longer/inductive wiring), which chokes the board's fast per-read current
   spikes -> voltage sag/dropouts at the board. USB masked it earlier by adding
   a stiff parallel power path.

### Why the capacitor helped (decoupling)
A local capacitor across the board's 5V/GND acts as a charge reservoir: it
supplies the fast per-read current spikes LOCALLY, so the rapid dI/dt no longer
has to fight through the DAQ path's series resistance and inductance (V=I*R and
V=L*dI/dt). It decouples the board's transient demand from a "weak" supply path.
  - E3631A-direct path is already stiff (low R/L) -> no cap needed (proven).
  - DAQ-in-series path is weak for transients -> cap needed to measure cleanly.
  - Deployment (direct battery) is stiff like the E3631A -> stable without a cap,
    but a decoupling cap is still good practice and will be included.

### Takeaways
- 8.40 mA (run 1) stands as the true 10 Hz deployment current.
- The faults were a BENCH MEASUREMENT ARTIFACT (DAQ series path), not a
  deployment flaw. Direct battery power in the field avoids it.
- For further clean DAQ captures: keep a decoupling cap at the board, and make
  the DAQ series connections as mechanically solid as possible.
- Watch item: one run showed sensor 6 (s6) column all-zero — check D9/A7/sensor
  contact; verify s6 varies in subsequent logs.

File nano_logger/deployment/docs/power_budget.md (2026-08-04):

# Nano logger — power budget & lifetime

Method: powered from Agilent E3631A bench supply (+6V output set to ~5.00 V)
into the Nano 5V pin; supply's own current readout = total system draw.
USB unplugged during measurement (board runs solely on the supply).

## D1 — Baseline (bench logger, no optimization)
Date: 2026-07-31
Setup: 03_nano_logger_bench.ino running; 3 sensors wired + RTC + SD; USB off.
Supply: 4.998 V, current = 0.051 A (51 mA), CV mode.

Interpretation:
  - Board awake 100% of the time (10 Hz loop, never sleeps).
  - Includes parasitic CH340 USB chip + power LED (~15-20 mA, removable on a
    deployment board or by moving to a bare ATmega328P).
  - Sensors powered continuously; SD idling.

Lifetime at 51 mA (constant):
  - 3000 mAh (1x 18650):   ~59 h  (~2.5 days)
  - 10000 mAh pack:        ~196 h (~8 days)
  -> A one-month target is NOT reachable at this draw. This is the number the
     sleep + power-gating stages must beat.

Targets for later stages: D2 sleep between samples, D3 sensor power-gating,
plus stripping parasitic loads. Goal: >= 1 month on a realistic pack.

## D2 (v1, RTC-alarm sleep) — SUPERSEDED
Date: 2026-07-31
Sketch: nano_logger_deploy_D2.ino (RTC DS3231 alarm as wake source, 1 Hz)
Result: sleep-wake mechanism confirmed working (once-per-second wakes; garbled
  serial across sleep = UART powering down = expected). Current dropped from
  51 mA baseline to ~37-40 mA steady with spikes to 51-60 mA on each wake.

Two problems found:
  1. Bug: after waking, the loop took multiple fast samples before sleeping
     again (files showed ~100 ms / ~19 ms row spacing, not clean 1 Hz).
  2. Design limitation: DS3231 alarm min interval = 1 s, forcing 1 Hz. This
     created a false 10Hz-vs-battery tradeoff.

Decision (per supervisor): the RTC alarm is the WRONG waker for pacing. Use the
ATmega's own watchdog/timer interrupt to wake every 100 ms -> keeps 10 Hz AND
sleeps between samples. RTC is retained for TIMESTAMPS only, not pacing. This
dissolves the 1Hz/10Hz tradeoff. Rebuilding D2 on this approach (see D2 v2).

Note: ~40 mA floor here is dominated by always-on parasitics (CH340 USB chip,
power LED, SD idle, RTC) that do NOT sleep — not the CPU. Big wins remain in
stripping those + sensor/SD gating, not in the sleep method itself.

Legacy-repo check: jamesaddy789 repo has NO sleep/timer-interrupt code (verified
by full grep) — it is a millis() busy-loop. The sleep approach is new to our
build, not inherited.

## D2 v2 — Sleep between samples (timer/watchdog wake, per supervisor)
Date: 2026-07-31
RTC now used for TIMESTAMPS ONLY; pacing done by the ATmega's own timer.
Measured on E3631A @ ~5 V into 5V pin, USB off (same setup as D1 baseline 51 mA).

Option A — D2a_wdt_8hz.ino: watchdog DEEP sleep (powerDown), SLEEP_120MS.
  Measured rate: ~6.6 Hz (120 ms WDT step + read/write overhead).
  Current: steady ~38 mA; spikes 41-60 mA on wake.  (-13 mA vs baseline)

Option B — D2b_timer_10hz.ino: Timer1 CTC 100 ms, light IDLE sleep.
  Measured rate: 9.9 Hz (exact 10 Hz; ms steps cleanly by 100).
  Current: steady ~45 mA; spikes 51-61 mA on wake.  (-6 mA vs baseline)

Finding: deeper sleep (A) saves ~7 mA more than light sleep (B), BUT both are
still ~38-45 mA — i.e. sleep depth is a MINOR lever. The floor is dominated by
always-on PARASITICS that do not sleep with the CPU: CH340 USB-serial chip,
power LED, SD card idle, DS3231. Removing those is the next (big) win.

Leaning: D2b (exact 10 Hz) is the likely deployment choice — keeps the full
spawning-FFT rate and gives up only ~7 mA, which parasitic-stripping (D3) will
dwarf. Decision deferred until D3 numbers are in.

Rate note: in D2a (power-down), millis() does not advance during sleep, so the
ms column is not a clock there — rate judged via RTC iso_time / sample count.
In D2b (IDLE), millis() runs normally and ms steps by ~100 as expected.

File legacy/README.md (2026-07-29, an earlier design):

# Legacy MBRACE code (reference only)

Archived snapshot of prior MBRACE / oyster-gape work by an earlier researcher,
kept here for context and reference only. It is NOT the active codebase — all
current firmware and analysis in this project are original work and live
elsewhere in this repo. Nothing in legacy/ is maintained; do not flash or deploy
it as-is.

## Credit
All code in this folder was written by James Curtis Addy
(GitHub: @jamesaddy789; commits authored as "Curtis" and "jamesaddy789").
Included with the permission of the project supervisor as continuation of the
JSU MBRACE project. Original authorship and credit remain with the author.
The source repositories carried no license file; this snapshot is retained for
internal research continuity with permission.

## Provenance (captured 2026-07-29)
- biosensor-firmware/ <- jamesaddy789/Biosensor-Code-JSU-Mbrace  (c3a0c95, 2021-05-24)
- matlab-analysis/    <- jamesaddy789/mbrace-oyster-matlab       (e8dafe5, 2020-10-31)
- python-tools/       <- jamesaddy789/Mbrace-Python              (8f42db7, 2020-01-09)
- android-app/        <- jamesaddy789/Mbrace-Oyster-Graph-Android-App (a907de5, 2019-09-13)

## What each part is
- biosensor-firmware/ : old Readers (Nano sensor sketches) + Senders (ESP/MKR SD+telemetry), I2C-linked. Source of the verified 6-channel Nano pin map.
- matlab-analysis/    : FFT / spawning-detection analysis; includes a real 2018 field dataset (.bin).
- python-tools/       : server-side + helper scripts that ingested the posted data blocks.
- android-app/        : Android app that graphed oyster gape (the prior live dashboard).

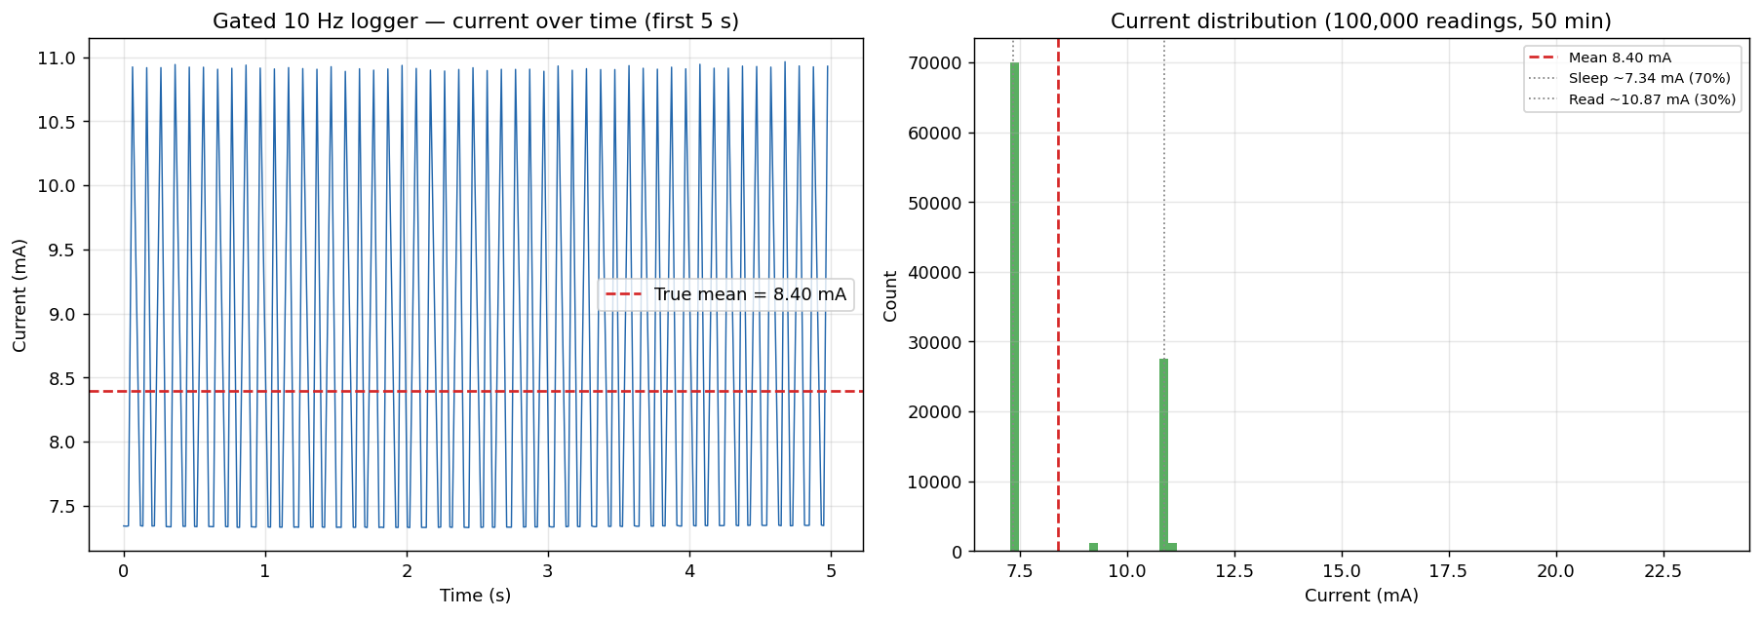
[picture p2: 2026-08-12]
nano_logger/deployment/docs/daq_current_analysis.png

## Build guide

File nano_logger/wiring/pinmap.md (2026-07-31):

# Nano logger — pin map (single source of truth)

Board: Arduino Nano (ATmega328P, 5 V). Sensors read directly, NO divider.

| Function | Nano pin(s) | Bus | Notes |
|---|---|---|---|
| Hall sensors (6) | A0, A1, A2, A3, A6, A7 | analog  | 5 V native; A4/A5 reserved |
| DS3231 RTC | A4 (SDA), A5 (SCL) | I2C | VCC=5V, GND=GND; no coin cell  |
| microSD module | D10 CS, D11 MOSI, D12 MISO, D13 SCK | SPI | 5 V level-shifted module |
| (deploy) sensor gate| D3 -> IRLB8721 gate | control | added in deployment layer |
| (deploy) RTC SQW | D2 | interrupt | added in deployment layer |

Note: D13 is SPI SCK *and* the onboard L LED — do not use the LED as a status
indicator; status goes to Serial.

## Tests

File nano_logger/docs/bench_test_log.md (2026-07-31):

# Nano logger — bench test log

## Step 1 — RTC alone (DS3231), no-coin-cell design
Date: 2026-07-30
Board: known-good Nano
Wiring: SDA=A4, SCL=A5, VCC=5V, GND=GND (HW-084 module, NO backup cell fitted)
Library: RTClib by Adafruit (NOT the similarly-named DS3231 library)
Sketch: sketches/01_rtc_test/01_rtc_test.ino

Design decision: module runs without a backup coin cell (per supervisor —
single main power source per unit). Consequence: RTC loses absolute time on
every power drop and lostPower() is true on each boot. Firmware therefore does
NOT auto-set to compile time (would stamp stale dates after a field reboot).
Instead it reports an "anchored" state (time_valid) and sets time only on an
explicit command. millis() is the always-valid relative axis; absolute time is
anchored explicitly and marked per-row. A coin cell can be added later with no
code change (time_valid would simply start at 1 on boot).

Bug found + fixed: initial sketch printed millis() inside the same snprintf as
other args; on AVR this mangled the value (ms froze ~7-8). Fixed by printing
millis() directly with Serial.println(). ms now increments ~1001/s as expected.

Result: PASS
  - RTC found; time increments 1 s per line.
  - time_valid=1 after set; 's' command works.
  - ms climbs ~1001 ms/line (the ~1 ms/line creep = delay + loop work; this is
    why the logger uses a fixed-cadence scheduler, not plain delay()).
Backup-cell check: N/A (no cell fitted by design).

Status: PASS

## Step 2 — SD card alone (CardInfo)
Date: 2026-07-30
Board: same known-good Nano (RTC still connected on I2C; no conflict)
Wiring: CS=D10, SCK=D13, MOSI=D11, MISO=D12, VCC=5V, GND=GND (HW-125 module)
Sketch: Arduino IDE example SD > CardInfo, chipSelect set to 10

Result: PASS
  - "Wiring is correct and a card is present."
  - Card type SDHC, Volume FAT32, ~29.1 GB, 61,037,344 total blocks read.
  - Confirms full SPI chain works, INCLUDING SCK/D13 health on this board
    (closes the earlier ICSP/SCK concern from board diagnosis).
Notes: "Initializing SD card..." prints twice = normal for CardInfo. Card
       empty (no files) = expected; logger will create files.

Status: PASS

## Step 3a — Sensors alone (3x HAL 2425 on A0/A1/A2)
Date: 2026-07-30
Board: same known-good Nano (peg rig from Board B; magnets in place)
Wiring: S1=A0, S2=A1, S3=A2; VDD=5V, GND=GND (5 V native, NO divider)
Sketch: sketches/03a_sensor_read_test/sensor_read_test.ino (delay 1000 for eyeball test)

Result: PASS
  - Noise floor at rest: spread 0-2 counts (occasionally 4) on all channels.
    -> 10-bit internal ADC is quiet here; effective resolution is good with
       no divider. Answers the resolution question with a measured number.
  - Resting values ~130-138 on all three (none pinned at 0 or 1023).
  - Each peg move swings ONLY its own channel (S1->~740, S2->~750, S3->~900),
    others stay flat -> sensors read + respond, no cross-talk.
  - Numbers ~4x smaller than ESP 12-bit path (0-1023 vs 0-4095) = expected.
Notes: large 'spread' values during a move = window capturing full travel,
       not noise. Print rate 1 Hz for readability; logger runs at 10 Hz.

Status: PASS

## Step 3 — Full logger (6 ch + RTC + SD, 10 Hz)
Date: 2026-07-30/31
Board: known-good Nano; 3 real sensors on A0/A1/A2 (peg rig), A3/A6/A7 unwired
Wiring: sensors 5V native; RTC I2C A4/A5; SD SPI CS=D10 (see pinmap.md)
Sketch: sketches/03_nano_logger_bench/03_nano_logger_bench.ino
Schema: iso_time,unix,ms,time_valid,node,sample,s1..s6
Reference data: LOG0002.CSV (1495 samples, ~150 s, ends time_valid=1)

Result: PASS (verified against logged data, with peg movement captured)
  - File-per-run: each power cycle creates a fresh LOGnnnn.CSV. Opening the
    Serial Monitor resets the Nano, so a short pre-monitor file appears + the
    real run file (e.g. LOG0001 tiny, LOG0002 = full run). Expected behavior.
  - Cadence: ms steps ~100/row; jitter absorbed by fixed-cadence scheduler
    (avg 10 Hz, no drift, no dropped samples). SD flush-every-row keeps up.
  - time_valid design proven: run starts time_valid=0 (year-2000 placeholder,
    RTC unanchored); after 's', rows flip to real 2026 time with time_valid=1.
    Logger never writes a wrong-but-plausible date.
  - MOVEMENT CAPTURED: pressing peg on A2/s3 swings s3 137->1010 and returns;
    s1/s2 stay flat (corr s3~s1=-0.16, s3~s2=-0.03). Real driven channels are
    clean and independent.

  FINDING — floating-pin ADC crosstalk (bench artifact, NOT a fault):
    Unwired A3/A6/A7 (s4/s5/s6) track A2/s3 almost perfectly
    (corr s3~s4=+1.00, s3~s5=+0.98, s3~s6=+0.97) but do NOT track A0/A1.
    Cause: single shared ADC + sample-and-hold; a floating high-impedance pin
    reads residual charge from the last DRIVEN channel sampled before it. Read
    order is {A0,A1,A2,A3,A6,A7}, so the ghost cascades from A2 -> A3 -> A6 ->
    A7, decaying (that's why s4>s5>s6). A0/A1 are earlier, already overwritten,
    so no ghost. Disappears in deployment (all 6 pins driven). Diagnostic:
    a channel suddenly correlating ~1.0 with the one read before it = a
    disconnected/failed sensor on that channel.

Status: PASS — Nano logger proven end to end, with movement captured.

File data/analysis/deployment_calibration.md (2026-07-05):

# Deployment calibration — Oyster_gape (MBRACE)

> **Current working approach: 25 mT + firmware tare** (2026-07-05, sketch
> `firmware/06_board_b_tare`). The 12 mT section below is retained for its offset
> findings and is **superseded** for the bench.

## Why we moved off 12 mT — the two-rulers / stacked-offset finding

The "distance" axis in every rig CSV is **carriage travel from the datum block**, not the
true magnet-to-sensor gap. The rig sweep starts with the magnet already standing off the
sensor — **measured ~5 mm** on the carriage — so **every CSV distance is ~5 mm short of the
true rig gap**. The peg mount then stacks its OWN, different offset on top (worked backward
from S3: 330 mV closed at a 12.4 mm caliper gap ⇒ ~1.5 mm peg offset). These offsets are
(a) not equal and (b) not the same sign, so **no single constant correction fixes both
setups** — which is what fooled the "peg is wider than the dead zone on paper" check twice.

Consequence at 12 mT: the window started at rig 11.0 mm and the closed peg landed just
below it → clamped ~300 mV (dead zone); small openings didn't register until ~1 mm in.

## Fix: 25 mT re-linearization (per-sensor, window 8.0–20.0)

Higher magnetic range shifts the active region toward **smaller** gaps, so at 25 mT the
window can start low (8.0) without hitting the steep shoulder / F:000000 spike. Re-done on
fresh pegs + fresh sensors. Bench-verified: closed pegs read **~448–464 mV (~8.5 mm, on
ramp)** and a realistic full-open reads **~2510 mV (~17.9 mm, on ramp)** — both gates passed
(closed off the floor, full-open under the ceiling).

| Channel | gape_mm line (abs) | Ramp (mm) | Floor / ceil (mV) | Linearity |
|:--:|:--:|:--:|:--:|:--:|
| **S1 → GPIO34** | (mV + 1368.4) / 214.7 | ~8.6–20.5 | 312 / 3150 | 1.5% |
| **S2 → GPIO35** | (mV + 1386.4) / 217.7 | ~8.3–20.3 | 284 / 3150 | 1.2% |
| **S3 → GPIO32** | (mV + 1355.5) / 216.9 | ~8.4–20.3 | 296 / 3150 | 1.7% |

Source: `data/sim_test_data/charac_S{1,2,3}_25mT_linearized_run1.csv`, window 8.0–20.0.
Slopes agree within ~1.4% (same tight clustering as 12 mT).

## The tare — what makes readings TRUE GAPE

Board B reports **gape = opening from closed**, not absolute separation:

    gape_mm = (mV − baseline_mV) / m

`baseline_mV` is each sensor's CLOSED reading, captured live. **The intercept b cancels in
the subtraction**, so gape is immune to the per-unit mounting offset — every unit zeroes to
itself and reads 0.00 mm closed. This is the mechanism that lets one lab calibration serve
many differently-mounted animals: linearize once, mount so closed sits on the ramp, tare
per unit at install.

- **Baseline capture:** automatic ~1.5 s after boot (hold pegs closed), **gated to on-ramp
  readings** — an off-ramp/clamped sensor is refused, not zeroed to junk. Re-baseline anytime
  via the serial `zero` command or the dashboard **Zero** button (needed after re-seating a
  peg or separating the magnet/sensor halves).
- **"Closed" band:** within **±0.05 mm** of baseline reads as closed (≈ noise floor, well
  below any real gape) so closed is steady, not flickering; any real press clears it instantly.
- Baselines live in RAM (re-captured each boot / on `zero`). **Deployment TODO:** persist to
  flash so they survive a power cycle (Phase 2).
- **Gauge auto-scales per unit:** the dashboard's bar + shell full-scale is each sensor's own
  physical max opening, `gmax = rampHi − baseline_mm`, computed live from the tare — no fixed
  full-scale constant. So the visual tracks each unit's real range (pegs now, oysters later)
  with nothing to change per deployment.

## Operating assumptions (stated, not proven)
- **Hinge-arc error is minimal** (professor's ruling for this oyster size/opening). The
  peg/oyster opens on an arc, not the carriage's straight line, so rig-calibrated mm are not
  *exactly* true mouth-gape mm at wide openings. The tare removes the *offset*; it does **not**
  remove this *arc-scale* error. Accepted assumption; revisit if a future animal opens wider.
- **Match the magnet:** the tare cancels offset, not slope. The magnet used at linearization
  must match the deployed magnet, or gape is scaled wrong.

## Deployment range (real oysters) — later
Professor prefers **3 mT** for large oysters (longest operating range, active region at
larger gaps). The *method* proven here (linearize → mount so closed is on-ramp → tare) is
identical at any range; deployment re-runs it at the chosen range once the oyster geometry
is known. 25 mT is the bench range only.

---

## Earlier: 12 mT bench (SUPERSEDED — retained for the offset findings)

All 3 peg sensors are linearized at **12 mT** on the rig (Board A), window
**11.0–24.0 mm**, SCALE 1024/29696, OUT 10/90, Extrapolation OFF. Each sensor keeps
its OWN mV->mm line for Board B:

    gape_mm = (mV - b) / m        (m = slope mV/mm, b = intercept mV)

**Label each physical sensor to match its Board B channel** (write it on the sensor):
- **S1 -> GPIO34**
- **S2 -> GPIO35**
- **S3 -> GPIO32**

| Sensor | Cal pt1 | Cal pt2 | Verify ramp (mm) | Linearity | Slope m (mV/mm) | Intercept b (mV) | Clamps lo/hi (mV) |
|:---:|:---:|:---:|:---:|:---:|:---:|:---:|:---:|
| S1 | 10796 | 2380 | 11.4–24.4 | 2.4% | 199.8 | -1810 | 299/3150 |
| S2 | 10156 | 2340 | 11.5–24.6 | 2.4% | 197.8 | -1799 | 317/3150 |
| S3 | 10720 | 2404 | 11.7–24.5 | 1.9% | 200.6 | -1863 | 316/3150 |

*(m, b) are computed by fitting the ramp region of each sensor's verify CSV. These
three lines go directly into Board B's firmware — one per channel.*

## Notes
- All three use the SAME range/window because the pegs are identical (~12 mm / 1.2 cm
  face-to-face closed, measured).
- If any sensor's transfer curve spikes at start, nudge the window start out (as we did
  tuning ranges) and re-note the window for that sensor.
- Board B has its own ADC + resistors, so m/b may shift slightly there; a 2-point check
  on Board B at a known closed/open gap will trim any offset (Phase 2 refinement).

---

## Board B conversion lines (FINAL — all 3 sensors linearized & verified)

| Channel | gape_mm = ... | Valid ramp (rig frame) | Low clamp (mV) |
|:---:|:---:|:---:|:---:|
| **S1 -> GPIO34** | (mV + 1810) / 199.8 | ~11.4–24.4 mm | ~299 |
| **S2 -> GPIO35** | (mV + 1799) / 197.8 | ~11.5–24.6 mm | ~317 |
| **S3 -> GPIO32** | (mV + 1863) / 200.6 | ~11.7–24.5 mm | ~316 |

`gape_mm` is distance in the **rig datum frame** (carriage travel from the block during
`verify`) — NOT the true magnet–sensor air gap and NOT the peg face-to-face gap. They
differ by a fixed mounting offset (the magnet + sensor bodies protrude into the peg gap),
so a peg *face* gap of X mm maps to a *smaller* rig-frame distance.

Outside the valid ramp the output is pinned at the clamp band (~300 mV low / ~3150 mV
high) and carries NO distance information — flag it (CLAMP); do not trust the mm.

### Bench finding (2026-07-03) — closed peg sits in the LOW clamp
**CORRECTION** to an earlier version of this file, which claimed the closed peg reads a
mid-ramp ~684–728 mV (OK). That was wrong: it was computed by plugging `mm = 12.7`
straight into the line, assuming peg-face-gap = rig-frame distance. It is not.

Ground truth (`data/charac_S{1,2,3}_12mT_linearized_run1.csv`): the ramp is flat at the
~300 mV LOW clamp from 0 out to ~11 mm (rig frame), then rises. On Board B a *closed*
bench peg (~12 mm / 1.2 cm face-to-face) reads **~300–335 mV on all three channels — the
LOW clamp**, i.e. at/just below the window floor, because the mounting offset maps it to
≤~11 mm rig-frame. A valid live gape reading therefore begins once a peg **opens** past
the window start; the opening excursion reads correctly on the ramp (bench-confirmed:
~979→1922 mV as a peg was pressed open).

Implication — with the current 12 mT window the CLOSED baseline is not directly readable
(clamped). To read it, either (a) lower the window start and re-linearize (mind the
steep-shoulder F:000000 spike rule), (b) increase the rest gap / recess the magnet+sensor
so closed lands inside the existing window, or (c) accept closed-as-clamped and read only
the opening excursion — fine for the bench proof.

### Consistency / scaling note
- Slopes agree within **1.4%**; linearity 1.9–2.4%. Mounting is repeatable and the parts
  are well matched.
- The main variation is in the **intercept (offset)** — at a common rig-frame distance
  the three lines differ by ~0.2 mm (b spans −1799 to −1863 mV). This is why per-sensor
  lines are kept: a single shared line would carry up to ~0.2 mm error across the ramp.
- **Scaling implication:** because the *shape* (slope) is so consistent and only the
  *offset* varies, at deployment scale you likely won't need a full 16-point
  linearization per unit — a full linearization on a few reference units plus a quick
  **single-point offset check** per deployed unit would capture the per-unit variation.
  (Deployment-scaling idea, not a Phase-1 action.)

**Status: linearization COMPLETE for all three peg sensors (S1/S2/S3) at 12 mT.**

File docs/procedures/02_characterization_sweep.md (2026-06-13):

# Procedure 02 — Characterization Sweep & Range Selection

**Goal:** capture the magnet's response curve (distance vs sensor output) and use
it to choose the magnetic range — **25 mT vs 50 mT** — for this magnet and the
~10 mm working window.

**Sketch:** `firmware/02_characterization_sweep/02_characterization_sweep.ino`
**Uses:** the Stage 01 constant, `0.001 mm/pulse`.

---

## Why this step decides the range

For the current magnet, the prior team's **±3 mT is blind below ~12 mm**, so in a
0–10 mm window it sees nothing. The candidates are:

- **±50 mT** — expected to climb cleanly from ~0 mm (full window usable, lower slope).
- **±25 mT** — more sensitive, but may clip in roughly the first ~2 mm.

We sweep at each and pick the **smallest range (highest sensitivity) whose curve
climbs cleanly across the whole window without a flat/clamped near end.**

---

## Order of operations (read this first)

This stage captures the **raw, un-linearized** sensor output. The sensor and
magnet must be physically mounted, and the magnetic range programmed, *before*
any sweep — the curve depends entirely on the geometry and range.

1. **Mount** the sensor in its fixed measurement position (sensitive face toward
   the magnet's travel axis); mount the magnet on the carriage, aligned, within
   the ~10 mm travel. **Freeze this geometry** — re-mounting later invalidates
   the characterization and any setpoints derived from it.
2. **Program the range** (Micronas app + programmer): Sensor Settings → Customer
   Setup → Magnetic Range → Write Customer Setup → Power On Reset. Leave
   linearization at **default (raw)**.
3. **Run standalone:** power the sensor from the board's 5 V, output → ÷2 divider
   → GPIO34. The Micronas app does **not** need to run during the sweep. If the
   programmer shares the OUT line, disconnect/power it down for the measurement
   so it doesn't load the signal.
4. **Sweep** with the ESP32 sketch; save the raw curve.
5. Repeat 2–4 for the other range, then choose.

The Micronas app returns in Stage 03 to ingest these raw curves and program the
setpoints. Characterization (here) is raw; linearization is later.

> Tip: the first time the sensor chain is live on a fresh rig, do one throwaway
> sweep at ±50 mT as a pure rig check (sensible climbing curve, sane noise, clean
> return) before the formal 25 vs 50 mT comparison.

## Prerequisites

- [ ] Stage 01 done; `MM_PER_PULSE = 0.001` is in the sketch.
- [ ] Sensor analog out → **2×10 kΩ ÷2 divider** → GPIO34. (0.1 µF cap optional.)
- [ ] Sensor powered from the **board's 5 V** (not the programmer), magnet on the carriage.
- [ ] In the Micronas tool, sensor **linearization left at default (raw)** — we
      are measuring the *uncorrected* curve. Only the **Magnetic Range** is set.
- [ ] `SWEEP_DISTANCE_MM` in the sketch fits your clear travel (default 9.0 mm).

## Wiring sanity check (do this first)

1. Upload the sketch, open Serial Monitor (115200, Newline).
2. Type `read`. You should get a stable millivolt value.
3. Jog the magnet a little (`500` = 0.5 mm) and `read` again — the value should
   **change**. If it doesn't move, or pins at 0 / max, fix wiring or the divider
   before sweeping.
   - Note the `sd` (noise) value. If it's large (tens of mV), that's the cue to
     add the 0.1 µF cap and/or raise `AVG_SAMPLES`.

---

## Running a sweep

1. Rest the carriage gently against the block, then nudge `200` away (backlash).
   This position is **travel = 0** for the sweep.
2. Type `sweep`. It steps away in 0.1 mm increments, averaging 200 reads per
   point, prints the CSV, then returns to start.
3. Copy everything between the `Distance_mm,Reading_mV,SD_mV` header and
   `# Sweep complete` and save it as a file in `data/` (see naming below).

> A Python logger that captures this automatically is the next build; for the
> first sweeps, Serial-Monitor copy-paste is fine.

## The range comparison

Run the sweep **at each range**, reprogramming the sensor in between:

1. Micronas tool → Sensor Settings → Customer Setup → **Magnetic Range = ±50 mT**
   → Write Customer Setup → Power On Reset.
2. Back to the sketch, `sweep`, save as `data/charac_50mT_run1.csv`.
3. Repeat for **±25 mT** → `data/charac_25mT_run1.csv`.
4. (Optional) a second run of each to check repeatability.

### What to look at

- **Near end (low mm):** is it a flat/clamped floor, or already climbing? A flat
  near end = clipping = blind zone for that range.
- **Slope:** steeper mV-per-mm = better resolution of small gape changes.
- **Monotonic:** the usable window must rise steadily (no flat or reversing
  regions) — that's the part we can linearize.

**Choose:** the most sensitive range that still climbs cleanly from travel 0
across the window. (Expected: 50 mT safe everywhere; 25 mT better slope if its
near end isn't clipped at your geometry.)

---

## Data file naming

```
data/charac_<range>_run<N>.csv      e.g. data/charac_50mT_run1.csv
```
Keep the header line in the file. Add the magnetic range and date as a comment
line at the top if your editor allows.

## Results — record here

| Range | File | Near end (clamped? from mm) | Slope (mV/mm, rough) | Usable window (mm) | Noise SD (mV) |
|---|---|---|---|---|---|
| 50 mT | | | | | |
| 25 mT | | | | | |

**Chosen range:** ____________  **Reason:** ____________
**Date / operator:** ____________

---

## Caveats

- Stay inside the travel; the sweep moves away from the block, so the only stall
  risk is the far end — make sure `SWEEP_DISTANCE_MM` leaves margin.
- The sensor must be **powered and outputting** during the sweep; if you only
  have it powered through the programmer, readings may be wrong.
- This curve is the **raw** (un-linearized) response. We linearize it in a later
  stage using these very measurements.

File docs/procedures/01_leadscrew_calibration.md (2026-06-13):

# Procedure 01 — Leadscrew mm-per-pulse Calibration

**Goal:** measure how far the actuator travels per STEP pulse, so every later
sweep reports true millimetres. This replaces the inherited `0.0001` constant
with a value we measure and document ourselves.

**Sketch:** `firmware/01_leadscrew_calibration/01_leadscrew_calibration.ino`
**Sensor needed:** no — this step is motion only.

---

## Background (why 2000 pulses = 1 revolution)

The Geckodrive G251 is a **fixed 10-microstep driver**: every STEP pulse is
1/10 of a full step. With a 200 full-step motor:

```
pulses per revolution = 200 full steps × 10 microsteps = 2000
```

The leadscrew *lead* (mm travelled per revolution) is a mechanical property of
the screw and is **not** in any datasheet, so we measure it.

---

## Pre-checks

- [ ] STEP → ESP32 GPIO18 → G251 Terminal 10
- [ ] DIR → ESP32 GPIO19 → G251 Terminal 9
- [ ] ESP32 GND ↔ G251 Terminal 12 (common logic ground) — **must** be shared
- [ ] G251 powered (15–50 VDC), motor phases A /A B /B wired, I-set resistor in place
- [ ] Carriage is free to move and you know its mechanical travel limits

## Setup

1. Arduino IDE → Board: **ESP32 Wrover Module**, Upload Speed 115200.
2. Upload the sketch.
3. Open Serial Monitor: **115200 baud**, line ending **Newline**.
   You should see the menu banner.

---

## Step A — Confirm direction

1. Type `100` and press enter. The carriage moves a small amount.
2. Watch which way it goes.
   - Moves **away** from the sensor → convention is correct (positive = away).
   - Moves **toward** the sensor → open the sketch, change
     `DIR_AWAY_LEVEL` from `HIGH` to `LOW`, re-upload, and re-test.
3. Record the result below.

## Step B — Measure travel

1. Move the carriage to a repeatable **datum** (a hard stop, or align a marked
   edge of the carriage to a ruler/caliper reference). Small jogs like `200`
   or `-200` help you nudge it there.
2. Type `zero`. The counter is now your datum.
3. Type `20000` (= 10 revolutions). Wait for `[done]`.
4. With a caliper or ruler, measure the **actual travel** from the datum.
   Record it in mm.
5. Type `mm <value>` (e.g. `mm 8.04`). The sketch prints mm/pulse,
   pulses/mm, and mm/rev.

## Step C — Repeat and average

Do Step B **at least 3 times**. Then repeat it moving in the **opposite
direction** (jog negative) — any difference between the away and toward results
is **backlash**, which we want to know about now.

---

## Results — measured 2026-06-12 (operator: temmy)

Method: cumulative jogs in the **away** direction from a single physical origin
(ruler mark), entering the total travel from that origin at each step (so each
row uses a longer baseline and is more accurate than the last). The toward
direction was checked separately and matched.

| Run | Direction | Cumulative pulses | Travel from origin (mm) | mm/pulse | mm/rev |
|-----|---|---|---|---|---|
| 1 | away | 20000 | 20.0 | 0.00100  | 2.0 |
| 2 | away | 40000 | 40.0 | 0.00100  | 2.0 |
| 3 | away | 60000 | 60.0 | 0.00100  | 2.0 |
| 4 | away | 80000 | 80.0 | 0.00100  | 2.0 |
| 5 | away | 100000 | 100.0 | 0.00100  | 2.0 |

**Toward direction:** repeated and consistent with the away results
(~0.001 mm/pulse), so **backlash is negligible** at this measurement resolution.

**Adopted mm/pulse:** **0.001**  (= 1000 pulses/mm, 2.0 mm/rev)

**Measurement note (honesty):** travel was read on a tape/ruler (~0.5 mm
resolution) and every point landed on an exact round number. The leadscrew lead
is very likely exactly 2.0 mm, but a small systematic scale error cannot be fully
ruled out from round readings alone. This does not affect downstream work — the
linearization step calibrates absolute distance and absorbs any small scale error
introduced here.

**Rig notes:** `DIR_AWAY_LEVEL = LOW`. The carriage rests against a hard block on
the sensor side; this is **not** a repeatable home (a limit switch is planned for
the positioning stage). All measured jogs move *away* from the block, so the
motor never stalls during a measurement run.

---

## Notes & gotchas

- **Missed steps corrupt the result.** If the motor sounds rough, buzzes, or
  stalls, it is dropping pulses. Increase `PULSE_HIGH_US` / `PULSE_LOW_US` in
  the sketch (slower = more reliable) and redo the run.
- **Stay inside the travel limits.** The sketch refuses any single move above
  `MAX_PULSES_PER_MOVE` (default 40000 = 20 rev) as a guard; jog in stages.
- Use the **longest** travel your screw allows for each run — more pulses per
  measurement means caliper reading error matters less.
- Once `mm/pulse` is adopted, it becomes a constant in the next sketch
  (the characterization sweep). We never hand-tune it again.

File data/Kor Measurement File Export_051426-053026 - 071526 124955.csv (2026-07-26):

Kor MEASUREMENT DATA FILE EXPORT
FILE CREATED: | 7/15/2026 5:50:39 PM
MEAN VALUE: |  |  |  |  |  | 4.86 | 1.40 | 12409.7 | 11904.1 | 7738 | 6.85 | 11849.7 | 80.4 | 6.12 | 80.4 | NA | -27.0 | 10.7 | 0.00 | 27.485 | 21.77 | 0 | 1.191
STANDARD DEVIATION: |  |  |  |  |  | 1.23 | 0.44 | 5874.4 | 5782.3 | 3758 | 3.59 | 5773.2 | 11.2 | 0.87 | 11.2 | 0.11 | 6.6 | 0.8 | 0.00 | 0.992 | 31.41 | 0 | 0.004
SENSOR SERIAL NUMBER: |  |  |  |  |  | 25H104806 | 25H104806 | 25H103291 | 25H103291 | 25H103291 | 25H103291 | 25H103291 | 25J103362 | 25J103362 | 25J103362 | 25J102175 | 25J102175 | 25J103045 | 25J103045 | 25H103291 | 25J103462 | 25J103462 | 25J102272
TIME (h:mm:ss tt) | DATE (M/d/yyyy) | FILE NAME | SITE NAME | USER ID | FAULT CODE | TAL PE RFU | CHLOROPHYLL RFU | COND µS/CM | SPCOND µS/CM | TDS MG/L | SAL PSU | NLF COND µS/CM | ODO % SAT | ODO MG/L | ODO % CB | PH | PH MV | CABLE PWR V | BATTERY V | TEMP °C | TURBIDITY FNU | TSS MG/L | WIPER POSITION VOLT
4:15:00 PM | 5/30/2026 | EXO_25J103045_051426_164500.bin | USM_1 | Canhao Wang | 0 | 4.30 | 1.25 | 3104.2 | 2873.5 | 1868 | 1.48 | 2848.2 | 91.3 | 6.94 | 91.3 | 7.10 | -25.1 | 8.0 | 0.00 | 29.202 | 32.04 | 0 | 1.190
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

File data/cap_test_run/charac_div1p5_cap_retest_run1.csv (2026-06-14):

# saved 2026-06-13T20:09:55
# range_label=div1p5_cap_retest
# --- characterization sweep ---
# step_mm=0.100 points=1001 avg_samples=200 settle_ms=100
Distance_mm | Reading_mV | SD_mV
0.000 | 2358 | 23.95
0.100 | 2359 | 18.94
0.200 | 2345 | 17.47
0.300 | 2326 | 23.90
0.400 | 2308 | 18.27
0.500 | 2290 | 19.21
0.600 | 2274 | 29.28
0.700 | 2257 | 34.73
0.800 | 2241 | 28.44
0.900 | 2223 | 17.12
1.000 | 2212 | 18.30
1.100 | 2198 | 30.14
1.200 | 2183 | 23.10
1.300 | 2173 | 18.77
1.400 | 2162 | 23.38
1.500 | 2148 | 19.03
1.600 | 2136 | 22.79
1.700 | 2126 | 18.51
1.800 | 2113 | 18.88
1.900 | 2103 | 26.04
2.000 | 2093 | 19.15
2.100 | 2083 | 18.33
2.200 | 2072 | 18.25
2.300 | 2062 | 18.41
2.400 | 2051 | 21.20
2.500 | 2042 | 23.32
2.600 | 2036 | 20.11
2.700 | 2032 | 32.16
2.800 | 2020 | 19.37
2.900 | 2012 | 19.67
3.000 | 2006 | 18.34
3.100 | 2000 | 29.59
3.200 | 1995 | 18.11
3.300 | 1987 | 18.81
3.400 | 1979 | 17.70
3.500 | 1971 | 18.08
3.600 | 1966 | 24.89
3.700 | 1962 | 27.22
3.800 | 1957 | 19.80
3.900 | 1951 | 18.39
4.000 | 1944 | 18.90
4.100 | 1940 | 17.60
4.200 | 1933 | 17.00
4.300 | 1932 | 22.24
4.400 | 1920 | 24.04
4.500 | 1917 | 18.22
4.600 | 1915 | 19.77
4.700 | 1908 | 18.36
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

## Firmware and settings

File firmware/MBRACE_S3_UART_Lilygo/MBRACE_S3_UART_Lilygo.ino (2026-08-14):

/*
12/24/2025: modify file name format to data_dev2_20251011213000UTC.csv, add AWS upload function by directly sending to S3 url
01/22/2026: Remove GPS module and just use LTE to get time, Pin18 19 instead of Pin32 33
01/29/2026: Uart pin change to 32(TX)  34(RX), 18(TX) 39(RX). 21,22,23,19 are used by GPS. 19 need set as output low
01/30/2026: if too many tryreplytimes will sending cmd request, stop, close uart and go sleep. Otherwise, it will keep get bad bytes forever when the sensor ESP32 abnormal.
            Another known problem is when getting HEAD if keeping err it will keep asking HEAD forever, but it should be fine if connection is good. Therefore, keep the code right now.
02/07/2026: If packid mismatch, but CRC correct, directly return false.
02/17/2026: Move jsonbody parameter to global char in static to avoid Heap fragmentation
02/23/2026: Sometimes cannot receive whole presignedurl packet reply
02/25/2026: Delete String to prevent memory leak
02/27/2026: sdwritertask stuck writing to SD card. Put uploading task after all of devices finish copying.
03/10/2026: CCHSEND fail and Retry always fail. add initSSL()
03/10/2026: Add more log message write to TF card to catch UART slow/stop issue
03/10/2026: sync time everytime after uploading to keep no shift
03/10/2026: initSSL() add mode selection 0/1 
07/15/2026: SIM7670G
07/25/2026: SONDE
08/04/2026：Upload log to AWS
*/
#define TINY_GSM_RX_BUFFER 1024  // Set RX buffer to 1Kb
#define CODE_VER "20260810_1408"
#define BANNER_STR "=== MBrace Receiver Starting  v" CODE_VER " ==="

// #define TEST_MODE
// See all AT commands, if wanted
// #define DUMP_AT_COMMANDS   //TEST


#define LILYGO_SIM7670G_S3_STAN
#define TINY_GSM_MODEM_SIM7670G
#define TINY_GSM_USE_GPRS true
#define TINY_GSM_USE_WIFI false

#include <SD.h>
#include <SPI.h>
#include <FS.h>
#include <miniz.h>  // miniz: https://github.com/richgel999/miniz
#include "utilities.h"
#include <esp_heap_caps.h>
#include <freertos/FreeRTOS.h>
#include <freertos/task.h>
#include <freertos/queue.h>
#include <Arduino.h>
#include <ArduinoJson.h>
#include <TinyGsmClient.h>
#include <SDI12.h>

// #include <TinyGPS++.h>
#include <time.h>
#include "driver/uart.h"
#include "soc/rtc.h"
#include "soc/rtc_cntl_reg.h"

#include <HTTPClient.h>
#include <ArduinoJson.h>
#include <Wire.h>  // 必须包含这个库来手动关闭它
#include "esp_err.h"
// #include <USB.h>  // ESP32-S3 USB CDC
#ifdef DUMP_AT_COMMANDS
#include <StreamDebugger.h>
StreamDebugger debugger(SerialAT, Serial);
TinyGsm modem(debugger);
#else
TinyGsm modem(SerialAT);
#endif

// #ifndef SerialGPS
// #define SerialGPS Serial2
// #endif

// // GPS pins for T-A7670 with GPS shield
// #define BOARD_GPS_TX_PIN                    21
// #define BOARD_GPS_RX_PIN                    22
// #define BOARD_GPS_PPS_PIN                   23
// #define BOARD_GPS_WAKEUP_PIN                19

// #define GPS_BAUD 9600
#define MODEM_ENABLE
// TinyGPSPlus gps;
TinyGsmClient client(modem);

#define CMD_REQ 0xA1
#define CMD_RES 0xA2
#define CMD_ERR 0xA3
#define CMD_HED 0xA4
#define CMD_DAT 0xA5
#define CMD_RTY 0xA6  //retry
#define CMD_YES 0xA7
#define CMD_WAT 0xA8
#define CMD_EOF 0xA9

#define RX1_PIN 47  // UART
#define TX1_PIN 14
#define RX2_PIN 37
#define TX2_PIN 21
#define UART_FREQ 500000

#define MODEM_BAUD 921600    //115200
#define CHUNK_SIZE 2048      // (1-2048) 2KB
#define BUF_SIZE 2048        //切换了部分 不懂哪里还有问题
#define SEND_TIMEOUT 20000   // CCHSEND 等待时间
#define MAX_RETRY 2          // 单 chunk 最大重发
#define S3_TIMEOUT 600000    // 整体等待时间  从 5分钟延长到10分钟 07/17/2026
#define S3_TIMEOUT_S 100000  // 短等待时间 for sonde

const char* API_HOST = "5pycakeikf.execute-api.us-east-1.amazonaws.com";
const char* API_PATH = "/dev/get-url";
const char* S3Url = "https://mbrace-data-csv-bucket.s3.amazonaws.com";
const char* S3Host = "mbrace-data-csv-bucket.s3.amazonaws.com";
// const char* S3Path = "/data";

static const int CCHMODEType = 0;



// 时钟监测变量
float measuredAPBFreq = 80;  // 默认80MHz
unsigned long lastClockCheck = 0;
const long CLOCK_CHECK_INTERVAL = 5000;  // 每5秒检查一次

const bool DEV_1 = true;  //both use Serial2
const bool DEV_2 = true;
const bool DEV_SONDE = false;
const bool DEV_LOG = true;
const int PayloadSize = 115;
const int PayloadSize_cmd = 9;
const int SleepDelay = 10000;
volatile bool isUploading_1_Finished = true;  // 初始为 false  07/18/2026： initial as true and change to false at the beginning of task. avoid wrong status
volatile bool isUploading_2_Finished = true;
volatile bool isUploading_Sonde_Finished = true;
volatile bool isUploading_Log_Finished = true;
volatile bool LTEStateIsOn = false;

// 02/17/2026: Move jsonbody parameter to global char in static to avoid Heap fragmentation
static char g_serialRxBuf[BUF_SIZE];
static int g_respLen = 0;

typedef struct __attribute__((packed)) {
  uint8_t cmd;
  uint8_t id;
  uint8_t len;
  uint8_t payload[PayloadSize];
  uint16_t crc;
} DataPacket;


typedef struct __attribute__((packed)) {
  uint8_t cmd;
  uint8_t id;
  uint8_t len;
  uint8_t payload_cmd[PayloadSize_cmd];
  uint16_t crc;
} CmdPacket;

// DataPacket pkt;

// const int MaxSendBytes = sizeof(DataPacket);
const int CmdPktBytes = sizeof(CmdPacket);
const int DatPktBytes = sizeof(DataPacket);
const int CrcSize = 2;
const int Crc_Len = DatPktBytes - CrcSize;
const int Crc_Len_Cmd = CmdPktBytes - CrcSize;

const int UartTimeout = 100;     // milliseconds
const int flushInterval = 1000;  //100, flush every N packets   was 10

QueueHandle_t dataQueue;  // for communication between I2C and SD writer
// A queue that holds 10 memory addresses (pointers)
QueueHandle_t g_uploadQueue = xQueueCreate(10, sizeof(char*));

File dataFile;
// File targetFile;
bool writing = false;
bool writingFile = false;
// char filename[64];
bool nextflag = false;
bool receiving = false;
long bytesReceived;
String currentFileName = "data.csv";
int TotalErrCount = 0;
int maxreplyretrytimes = 10;
long TotalRcvdSize;


int errorCount = 0;
bool responseReceived = false;

#ifdef TEST_MODE
int Recv_count = 0;
#endif

int packetCounter = 0;
uint16_t crc = 0xFFFF;
uint8_t packetId = 0;  // Packet number

// File logFile;

// Log file name
const char* logFileName = "/rcv_Gulfport.log";

//03/04/2026:
String g_responseText;

#define MaxFilenameLength 64
struct FilePacket {
  char filename[MaxFilenameLength];  // using 32 + 1 (\0) chars right now. "/data_dev1_20250904172910UTC.csv"
  int size;
  bool end = false;
  uint8_t data[PayloadSize];
  int len;
};

//08/04/2026：Upload log to AWS
// ===== 上传周期配置 =====
enum IntervalMode {
  INTERVAL_2MIN_TEST,  // 测试用，固定2分钟（可选保留，方便调试）
  INTERVAL_HOURLY,
  INTERVAL_HALF_DAY,  // 每12小时上传一次
  INTERVAL_DAYLY      // 每24小时上传一次
};

uint64_t getIntervalSec(IntervalMode mode) {
  switch (mode) {
    case INTERVAL_2MIN_TEST: return 120;
    case INTERVAL_HOURLY: return 3600;
    case INTERVAL_HALF_DAY: return 43200;  // 12小时
    case INTERVAL_DAYLY: return 86400;     // 24小时
    default: return 3600;
  }
}

// ⚠️ 在这里切换你想要的上传频率
IntervalMode g_dat_Interval = INTERVAL_HOURLY;
IntervalMode g_log_Interval = INTERVAL_2MIN_TEST;


//07/25/2026: SONDE
#define SONDE_DATA_PIN 36  // ⚠️ 替换成你实测确认空闲、且已接好电平转换模块的GPIO
SDI12 sondeBus(SONDE_DATA_PIN);

const uint64_t SONDE_SAMPLE_INTERVAL_SEC = 900;  // 15分钟

const char* sondeAddress = "0";  // ⚠️ 请在KorEXO里核实实际地址
const char* sondeFileName = "/sonde_current.csv";
const char* sondeFieldNames = "Temp_C,DO_mgL,SpCond_uScm,pH";  // 按KorEXO实际勾选顺序调整

// 手动按字节读取，带超时和"空闲间隔"判断，比 readStringUntil 更可控、更方便调试
String readSDI12Raw(uint32_t timeoutMs, uint32_t idleGapMs = 200) {
  String resp = "";
  uint32_t lastByteTime = millis();
  uint32_t start = millis();

  while (millis() - start < timeoutMs) {
    while (sondeBus.available()) {
      char c = sondeBus.read();
      resp += c;
      lastByteTime = millis();
    }
    if (resp.length() > 0 && (millis() - lastByteTime > idleGapMs)) {
      break;  // 连续idleGapMs没有新字节，认为这条响应结束
    }
  }
  return resp;
}


bool readSondeOnce(String& outLine) {
  sondeBus.begin();
  delay(100);  // 库文档建议begin后给一点稳定时间

  String cmd = String(sondeAddress) + "M!";
  sondeBus.sendCommand(cmd);

  String mResp = readSDI12Raw(2000);
  mResp.trim();

  Serial.print("[Sonde] M! raw: ");
  for (size_t i = 0; i < mResp.length(); i++) Serial.printf("%02X ", (uint8_t)mResp[i]);
  Serial.println();

  if (mResp.length() < 5) {
    Serial.println("Err_readSondeOnce: no reply to M!");
    sondeBus.end();
    return false;
  }

  // 标准格式 atttn: a=地址, ttt=等待秒数(3位), n=返回数据个数(1位)
  int waitSec = mResp.substring(1, 4).toInt();
  delay((waitSec > 0 ? waitSec : 1) * 1000UL + 300);

  String dcmd = String(sondeAddress) + "D0!";
  sondeBus.sendCommand(dcmd);

  String data = readSDI12Raw(2000);
  data.trim();

  Serial.print("[Sonde] D0! raw: ");
  for (size_t i = 0; i < data.length(); i++) Serial.printf("%02X ", (uint8_t)data[i]);
  Serial.println();

  sondeBus.end();

  if (data.length() < 3) {
    Serial.println("Err_readSondeOnce: no data from D0!");
    return false;
  }

  // 去掉开头地址位，把 +/- 分隔的数值转成逗号分隔
  String values = data.substring(1);
  values.replace("+", ",+");
  values.replace("-", ",-");
  if (values.startsWith(",")) values = values.substring(1);

  outLine = printLocalTime(1) + "," + values;
  return true;
}



void appendSondeReading() {
  String line;
  if (!readSondeOnce(line)) {
    logMessage("Err_appendSondeReading: sonde read failed");
    return;
  }

  bool isNewFile = !SD.exists(sondeFileName);
  File f = SD.open(sondeFileName, FILE_APPEND);
  if (!f) {
    logMessage("Err_appendSondeReading: cannot open sonde file");
    return;
  }
  if (isNewFile) {
    f.print("Timestamp,");
    f.println(sondeFieldNames);
  }
  f.println(line);
  f.close();

  Serial.print("Sonde reading appended: ");
  Serial.println(line);
}



void enqueueSondeFileForUpload() {
  if (!SD.exists(sondeFileName)) {
    Serial.println("No Sonde file");
    isUploading_Sonde_Finished = true;
    return;
  }

  String archivedName = "/sond_" + printLocalTime(0) + "U.csv";
  SD.rename(sondeFileName, archivedName.c_str());

  char* ptr_filename = strdup(archivedName.c_str());
  xQueueSend(g_uploadQueue, &ptr_filename, portMAX_DELAY);
  Serial.print("Sonde file enqueued for upload: ");
  Serial.println(archivedName);
  isUploading_Sonde_Finished = false;
}



void myWaitResponse(const int timeout) {
  unsigned long start = millis();
  while (millis() - start < timeout) {
    // 只要有数据就读，没数据立刻跳出，不等待回车
    while (SerialAT.available()) {
      char c = SerialAT.read();
#ifdef DUMP_AT_COMMANDS
      Serial.write(c);  // 直接字节输出，不会因为没有换行符而卡顿
#endif
    }
    yield();  // 释放 CPU 给 ESP32 的后台任务
  }
}


//03/10/2026: initSSL() add mode selection 0/1
bool initSSL(const int& mode) {
  myWaitResponse(100);
  if (mode == 0) {
    call_cchclosestop();
    modem.sendAT(GF("+CCHSET=1,0"));

    // A76XX Series_AT Command Manual_V2.01
    // Defined Values
    // <report_send_result> Whether to report result of CCHSEND, the default value is 0:
    // 0 No.
    // 1 Yes. Module will report +CCHSEND: <session_id>,<err> to MCU when complete sending data.
    // <recv_mode> The receiving mode, the default value is 0:
    // 0 Output the data to MCU whenever received data.
    // 1 Module caches the received data and notifies MCU with +CCHEVENT: <session_id>, RECV EVENT.
    // MCU can use AT+CCHRECV to receive the cached data (only in manual receiving mode).

    //CCHSET=1,0 : presigned url too long and will lose bytes
    //CCHSET=1,1 : connection close and cannot read

    if (modem.waitResponse(SEND_TIMEOUT) != 1) {
      Serial.println("CCHSET Failed!");
      return false;
    }

    modem.sendAT(GF("+CCHMODE="), CCHMODEType);  //modem.sendAT("+CCHMODE=" + CCHMODEType);
    if (modem.waitResponse(SEND_TIMEOUT) != 1) {
      Serial.println("CCHMODE Failed!");
      return false;
    }

    modem.sendAT(GF("+CCHSTART"));
    if (modem.waitResponse(SEND_TIMEOUT, "+CCHSTART: 0") != 1) {
      Serial.println("CCHSTART Failed!");
      return false;
    }

    modem.sendAT(GF("+CSSLCFG=\"sslversion\",0,4"));
    if (modem.waitResponse(SEND_TIMEOUT) != 1) {
      Serial.println("CSSLCFG Failed!");
      return false;
    }

    modem.sendAT(GF("+CSSLCFG=\"authmode\",0,0"));
    if (modem.waitResponse(SEND_TIMEOUT) != 1) {
      Serial.println("CSSLCFG Failed!");
      return false;
    }

  } else {

    modem.sendAT(GF("+CCHSTART"));
    if (modem.waitResponse(SEND_TIMEOUT) != 1) {
      Serial.println("CCHSTART Failed!");
      return false;
    }

    modem.sendAT(GF("+CSSLCFG=\"sslversion\",0,4"));
    if (modem.waitResponse(SEND_TIMEOUT) != 1) {
      Serial.println("CSSLCFG Failed!");
      return false;
    }
  }




  return true;
}



bool openConnection(const char* host, int port) {
  //07152026  check if is clean before CCHOPEN
  int tmpval;
  modem.sendAT(GF("+CCHOPEN?"));
  tmpval = modem.waitResponse(SEND_TIMEOUT, g_responseText, GF("+CCHOPEN: 0,\"\",,,"), GF("ERROR"), GF("OK"));
  Serial.print("CCHOPEN state : ");
  Serial.println(tmpval);
  Serial.print("Modem output: ");
  Serial.println(g_responseText);
  g_responseText = "";

  modem.sendAT(GF("+CCHOPEN=0,\""), host, GF("\","), port, GF(",2"));

  if (CCHMODEType == 0) {
    if (modem.waitResponse(SEND_TIMEOUT, "+CCHOPEN: 0,0") != 1) {
      Serial.println("CCHOPEN Failed!");
      return false;
    }

  } else if (CCHMODEType == 1) {
    // if (modem.waitResponse(SEND_TIMEOUT,"CONNECT 115200",) != 1) {//921600
    //   Serial.println("CCHOPEN Failed!");
    //   return false;

    unsigned long start = millis();
    String rescode = "FAIL";
    while (millis() - start < 5000) {  // 5s 超时
      if (SerialAT.available()) {
        String line = SerialAT.readStringUntil('\n');
        line.trim();
        Serial.println(line);  // 打印模块返回

        if (line.startsWith("CONNECT ")) {
          int firstComma = line.indexOf(' ');
          rescode = line.substring(firstComma + 1);
          break;
        }
      }
    }
    if (rescode == "FAIL") {
      Serial.println("CCHOPEN Failed!");
      return false;
    }
  } else {
    Serial.println("CCHOPEN CCHMODEType error!");
    return false;
  }

  return true;
}
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
void loop() {
  unsigned long timeout;
  esp_err_t err;
  time_t now = time(NULL);

  logMessage("lilygo wake up");
  checkmemory();
  now = time(NULL);

  //07/25/2026: SONDE
  bool sondeDue = (next_sonde_sample_sec == 0) || (now >= (time_t)next_sonde_sample_sec);
  bool datUploadDue = (next_dat_upload_sec == 0) || (now >= (time_t)next_dat_upload_sec);
  bool logUploadDue = (next_log_upload_sec == 0) || (now >= (time_t)next_log_upload_sec);

  logMessage("Sonde sample due: " + String((long)((time_t)next_sonde_sample_sec - now)) + "sec");
  logMessage("Data upload due: " + String((long)((time_t)next_sonde_sample_sec - now)) + "sec");
  logMessage("Log upload due: " + String((long)((time_t)next_sonde_sample_sec - now)) + "sec");

  // sonde采样：不需要modem，独立执行，跟上传周期无关
  if (DEV_SONDE && sondeDue) {
    logMessage("Sonde sample due");
    appendSondeReading();
  }

  if (datUploadDue || logUploadDue) {
    Serial.println("[Command] Starting transfer...");

    if (datUploadDue) {
      if (DEV_1) {
        logMessage("[DEV_1] ...");
        isUploading_1_Finished = false;
        if (!FilecopyTask(Serial2, sdWriterHandle_1, RX1_PIN, TX1_PIN, "1")) {
          logMessage("Err_loop: DEV_1 FilecopyTask failed");

          if (Serial2) {
            // 04/01/2026: reduce power consumption
            Serial2.flush();
            Serial2.end();
          }
          // gpio_reset_pin((gpio_num_t)RX1_PIN);
          // gpio_reset_pin((gpio_num_t)TX1_PIN);
          pinMode(RX1_PIN, INPUT_PULLDOWN);
          pinMode(TX1_PIN, INPUT_PULLDOWN);
          isUploading_1_Finished = true;
        }
      }

      // checkmemory();

      // vTaskDelay(30000 / portTICK_PERIOD_MS);//test pin still get high signal after end and while connect dev2 serial

      if (DEV_2) {
        logMessage("[DEV_2] ...");
        isUploading_2_Finished = false;
        if (!FilecopyTask(Serial2, sdWriterHandle_2, RX2_PIN, TX2_PIN, "2")) {
          logMessage("Err_loop: DEV_2 FilecopyTask failed");
          if (Serial2) {
            // 04/01/2026: reduce power consumption
            Serial2.flush();
            Serial2.end();
          }
          // gpio_reset_pin((gpio_num_t)RX2_PIN);
          // gpio_reset_pin((gpio_num_t)TX2_PIN);
          pinMode(RX2_PIN, INPUT_PULLDOWN);  //34,39 dont have internal pulldown res
          pinMode(TX2_PIN, INPUT_PULLDOWN);
          isUploading_2_Finished = true;
        }
      }

      if (DEV_SONDE) {
        enqueueSondeFileForUpload();  // 把攒好的 sonde 数据也改名塞进这一轮上传..
      }
    }

    //08/04/2026：Upload log to AWS
    if (DEV_LOG && logUploadDue) {
      enqueueLogFileForUpload();
    }

    //02/27/2026: sdwritertask stuck writing to SD card
    StartFileUploadTask(g_UploadTaskHandle);


    if (datUploadDue) {
      if (DEV_1) {
        timeout = millis() + S3_TIMEOUT;
        while (!isUploading_1_Finished && millis() < timeout) {
          Serial.println("wait dev1 uploading...");
          vTaskDelay(10000 / portTICK_PERIOD_MS);
        }
        if (!isUploading_1_Finished) {
          Serial.println("dev1 uploading timeout");
        }
      }
      if (DEV_2) {
        timeout = millis() + S3_TIMEOUT;
        while (!isUploading_2_Finished && millis() < timeout) {
          Serial.println("wait dev2 uploading...");
          vTaskDelay(10000 / portTICK_PERIOD_MS);
        }
        if (!isUploading_2_Finished) {
          Serial.println("dev2 uploading timeout");
        }
      }
      if (DEV_SONDE) {
        timeout = millis() + S3_TIMEOUT_S;
        while (!isUploading_Sonde_Finished && millis() < timeout) {
          Serial.println("wait sonde uploading...");
          vTaskDelay(10000 / portTICK_PERIOD_MS);
        }
        if (!isUploading_Sonde_Finished) {
          Serial.println("sonde uploading timeout");
        }
      }
    }

    if (DEV_LOG && logUploadDue) {
      timeout = millis() + S3_TIMEOUT_S;
      while (!isUploading_Log_Finished && millis() < timeout) {
        Serial.println("wait log uploading...");
        vTaskDelay(10000 / portTICK_PERIOD_MS);
      }
      if (!isUploading_Log_Finished) {
        Serial.println("log uploading timeout");
      }
    }

    vTaskDelay(500 / portTICK_PERIOD_MS);

    if (g_UploadTaskHandle != NULL) {
      vTaskDelete(g_UploadTaskHandle);
      g_UploadTaskHandle = NULL;
      logMessage("Err_loop: g_UploadTaskHandle didn't close!");
    }
    vTaskDelay(500 / portTICK_PERIOD_MS);

    //03/10/2026: sync time everytime after uploading to keep no shift
    initializeTime();
    logMessage("UTC: " + printLocalTime(0) + "UTC, System sync time");

    shutdownModem();
  }

  // Set next wake up time
  struct tm timeinfo;

  if (!getLocalTime(&timeinfo)) {
    // If time isn't set yet, fallback to a safe fixed sleep
    if (++g_transtimes <= 2) {
      err = esp_sleep_enable_timer_wakeup(60000000);
      Serial.printf("enable wakeup err = %s (%d)\n",
                    esp_err_to_name(err), err);
    } else {
      err = esp_sleep_enable_timer_wakeup(3300000000);  // 60min
      Serial.printf("enable wakeup err = %s (%d)\n",
                    esp_err_to_name(err), err);
    }
  } else {
    now = time(NULL);  // Get current Unix timestamp in seconds
    uint64_t dat_interval;
    uint64_t log_interval = getIntervalSec(g_log_Interval);

    // 1. Determine the interval based on transtimes
    if (++g_transtimes <= 2) {
      dat_interval = 120;  // 2 minutes
      // 2. Initialize the target if it's the first run
      if (next_sonde_sample_sec == 0) {
        next_sonde_sample_sec = now + SONDE_SAMPLE_INTERVAL_SEC;
      }
      if (next_dat_upload_sec == 0) {
        next_dat_upload_sec = now + dat_interval;
      }
      if (next_log_upload_sec == 0) {
        next_log_upload_sec = now + log_interval;
      }
    } else {
      dat_interval = getIntervalSec(g_dat_Interval);
    }

    // 3. Calculate sleep time in seconds, then convert to microseconds
    //07/25/2026: SONDE 取3个锚点里最近的那个作为本次睡眠时长
    int64_t deltaSample = (int64_t)next_sonde_sample_sec - now;
    int64_t deltaData = (int64_t)next_dat_upload_sec - now;
    int64_t deltaLog = (int64_t)next_log_upload_sec - now;
    int64_t sleepDeltaSec = min(deltaSample, min(deltaData, deltaLog));
    if (sleepDeltaSec < 0) sleepDeltaSec = 0;

    char buf[24];
    snprintf(buf, sizeof(buf), "%lld", sleepDeltaSec);
    logMessage(String("Sleep for: ") + buf + " seconds");

    // Set wakeup (Seconds * 1,000,000 = Microseconds)
    err = esp_sleep_enable_timer_wakeup((uint64_t)sleepDeltaSec * 1000000ULL);
    Serial.printf("enable wakeup err = %s (%d)\n", esp_err_to_name(err), err);

    // 4.检查哪些变量等于这个最小值 Update the anchor for the next cycle
    if (deltaSample == sleepDeltaSec) {
      next_sonde_sample_sec += SONDE_SAMPLE_INTERVAL_SEC;
    }
    if (deltaData == sleepDeltaSec) {
      next_dat_upload_sec += dat_interval;
    }
    if (deltaLog == sleepDeltaSec) {
      next_log_upload_sec += log_interval;
    }
  }

  checkmemory();

  //03/26/2026
  // SD.end();
  //04/01/2026: wake up then restart issue
  endSDCard();

  vTaskDelay(2000 / portTICK_PERIOD_MS);


  err = esp_light_sleep_start();
  Serial.printf("light sleep err = %s (%d)\n", esp_err_to_name(err), err);


  //03/31/2026: battery mode sometimes restart after waking up
  vTaskDelay(500 / portTICK_PERIOD_MS);

  // //07152026  test
  // USB.begin();
  // Serial.begin(115200);

  //03/26/2026: miss log after wake up
  // uint8_t cardType = SD.cardType();
  // if (cardType == CARD_NONE) {
  //     Serial.println("No SD card attached");
  //     // return;
  // }
  // else{
  //   logMessage("waked up and attached SD");
  // }
  initializeSDCard();

  // // Nothing here; all work done in RTOS tasks
  // vTaskDelay(portMAX_DELAY);
}

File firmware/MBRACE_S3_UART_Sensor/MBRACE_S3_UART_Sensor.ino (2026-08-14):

// === ESP32 UART Slave + Sensor + SD Card (FreeRTOS, PacketID, Resend Support) ===
//UART: 21,22
//SD_SPI: 5,18,19,23
//Sensor: 36,39,34,35,32,33,25,26,27,14,12,13,4,15
//SensorPower: 2 (with LED)  //test if in sleep will power auto down?  No.
//08112026: g_packetId didn't reset while timeout happen, 实际上因为没有清空queue导致之前的残留
//08112026: delete file no matter success or failed

#include <Arduino.h>
#include <SD.h>
#include <SPI.h>
#include <freertos/FreeRTOS.h>
#include <freertos/task.h>
#include <freertos/queue.h>
#include <esp_heap_caps.h>
#include <FS.h>
#include <Wire.h> //01232026 手动关闭I2C

#define CMD_TME 0xA0
#define CMD_REQ 0xA1
#define CMD_RES 0xA2
#define CMD_ERR 0xA3
#define CMD_HED 0xA4
#define CMD_DAT 0xA5
#define CMD_RTY 0xA6  //retry
#define CMD_YES 0xA7
#define CMD_WAT 0xA8
#define CMD_EOF 0xA9


#define CS_PIN 5
#define RX_PIN 21 // UART  32, 33  ; 16, 17 //s3 use 8,9 cause trash bytes
#define TX_PIN 22
#define UART_FREQ 500000//2000000 
#define S3_TIMEOUT   300000    // CCHSEND 等待时间
// #define TEST_MODE

const int PayloadSize =115;// 240;
const int PayloadSize_cmd = 9;

typedef struct __attribute__((packed)) {
  uint8_t cmd;
  uint8_t id;
  uint8_t len;
  uint8_t payload[PayloadSize];
  uint16_t crc;
} DataPacket;

// DataPacket pkt;

typedef struct __attribute__((packed)) {
  uint8_t cmd;
  uint8_t id;
  uint8_t len;
  uint8_t payload_cmd[PayloadSize_cmd];
  uint16_t crc;
} CmdPacket;


const int DatPktBytes = sizeof(DataPacket);
const int CmdPktBytes = sizeof(CmdPacket);
const int CrcSize = 2;
const int Crc_Len = DatPktBytes - CrcSize;
const int Crc_Len_Cmd = CmdPktBytes - CrcSize;

QueueHandle_t packetQueue;

File g_dataFile;
File g_sendFile;//20260422
// TaskHandle_t xWatchdogTaskHandle = NULL;
bool Flag_xWatchdogTaskHandle = false;

uint8_t g_packetId = 0;  // Packet number
String g_currentFileName = "/data.csv";
// String HeadStr;
int filePointer = 0;
bool sendingtask = false;
volatile bool IsReadytosend = false;
bool headerSent = false;
unsigned long UartTimeout;

int errorCount=0;
long totalPackets = 0;
int IsUsingUart = -1;
DataPacket LastPacket;
DataPacket HeadPacket;
bool IsHeadReady = false;
// String datetime_rcv="0";
// unsigned long datetime_t = 0; //最大值是 4,294,967,295 毫秒，大约 49.71 天

#define SENSOR_COUNT 14
String sensorReadings[SENSOR_COUNT];

int sensorPinValues[SENSOR_COUNT] = {36,39,34,35,32,33,25,26,27,14,12,13,4,15};
int sensorPowerSwPin = 2;

bool RxPinHighDetected = false;

// CRC16
uint16_t crc16_update(uint16_t crc, uint8_t data) {
  crc ^= data;
  for (int i = 0; i < 8; ++i) {
    if (crc & 1) crc = (crc >> 1) ^ 0xA001;
    else crc = crc >> 1;
  }
  return crc;
}

uint16_t calculateCRC(const uint8_t* data, size_t len) {
  uint16_t crc = 0xFFFF;
  for (size_t i = 0; i < len; ++i) {
    crc = crc16_update(crc, data[i]);
  }
  return crc;
}

void BuildPacket(DataPacket &packet, const uint8_t &cmd, const int &id, const uint8_t *body, const size_t &body_len) {
  packet.cmd = cmd;
  packet.id = id;
  packet.len = body_len;
  memcpy(packet.payload, body, body_len);
  packet.crc = calculateCRC((uint8_t*)&packet, Crc_Len);
}

void filePacketTask(void* pv) {
  // int queuecount;
  String headStr; 
  TaskHandle_t* handlePtr = (TaskHandle_t*)pv;
  
#ifdef TEST_MODE
    Serial.println("filePacketTask: begin run!"); 
#endif
  while(!IsReadytosend){
#ifdef TEST_MODE
    Serial.println("filePacketTask: not readytosend"); 
#endif
    vTaskDelay(2000 / portTICK_PERIOD_MS);
  } // need mordify to xSemaphoreTake

#ifdef TEST_MODE
  Serial.println("filePacketTask: readytosend"); 
#endif

  g_sendFile = SD.open(g_currentFileName);
  if (!g_sendFile) { 
    sendingtask = false;
    Serial.println("Err_filePacketTask: fail to open sendFile");  //may need reply fail to master  
    headStr = g_currentFileName + ":err";
    HeadPacket.cmd = CMD_HED;
    HeadPacket.id = ++g_packetId; //1
    HeadPacket.len =headStr.length();
    memcpy(HeadPacket.payload, (uint8_t*)headStr.c_str(), headStr.length()); 
    HeadPacket.crc = calculateCRC((uint8_t*)&HeadPacket, Crc_Len);
    IsHeadReady = true;
    Serial.println("filePacketTask: errheader sent");  
    UartTimeout = millis() + 20000;// let it shutdown earlier
    vTaskDelay(20 / portTICK_PERIOD_MS);
    vTaskDelete(NULL);     //del the task and won't run lately code
  }


  // Send header
  headStr = g_currentFileName + ":" + String(g_sendFile.size());
  HeadPacket.cmd = CMD_HED;
  HeadPacket.id = ++g_packetId; //1
  HeadPacket.len =headStr.length();
  memcpy(HeadPacket.payload, (uint8_t*)headStr.c_str(), headStr.length()); 
  HeadPacket.crc = calculateCRC((uint8_t*)&HeadPacket, Crc_Len);
  IsHeadReady = true;
#ifdef TEST_MODE
    Serial.println("filePacketTask: headStr = " + headStr); 
    Serial.printf("filePacketTask: headStr.length() = %d\n",headStr.length()); 
    Serial.printf("filePacketTask: estimate pkg count = %d\n",long(g_sendFile.size()/PayloadSize)); 
#endif
  vTaskDelay(20 / portTICK_PERIOD_MS);


#ifdef TEST_MODE
  Serial.println("filePacketTask: Loading file..."); 
#endif

  // Send body packets
  while (g_sendFile.available()) {
    // queuecount = uxQueueMessagesWaiting(packetQueue);
    uint8_t body[PayloadSize] = {0};
    size_t len = g_sendFile.read(body, PayloadSize);
    DataPacket packet;
    BuildPacket(packet, CMD_DAT, ++g_packetId, body, len);  //start from 2
    xQueueSend(packetQueue, &packet, portMAX_DELAY);//满了会自动阻塞等待
  }
#ifdef TEST_MODE
  Serial.println("filePacketTask: file end"); 
#endif
  // Send EOF   
  DataPacket eof;
  BuildPacket(eof, CMD_EOF, ++g_packetId, NULL, 0);
  xQueueSend(packetQueue, &eof, portMAX_DELAY);
  Serial.println("filePacketTask: eof sent & remove file");
  g_sendFile.close();
  SD.remove(g_currentFileName);
  // sendingtask = false;
  vTaskDelete(NULL);     //del the task and won't run lately code
}



void onReceive(int len) {
  CmdPacket cmdpkt;

  if (len != CmdPktBytes) {
    Serial.printf("❌ len = %d    CmdPktBytes = %d\n", len,CmdPktBytes);
    Serial.println("❌ Wrong packet size");
    errorCount++;
    uint8_t rcv[len]={0};
    Serial1.readBytes(rcv, len);

#ifdef TEST_MODE
    Serial.println("debug rcv wrong size cmd:");
      // 打印索引行
    for (size_t j = 0; j < len; ++j) {
      Serial.printf("%3d ", j);
    }
    Serial.println();

    // 打印数据行
    for (size_t j = 0; j < len; ++j) {
      Serial.printf(" %02X ", rcv[j]);
    }
    Serial.println();
#endif
    
    ++errorCount;
    return;
  }

  Serial1.readBytes((char*)&cmdpkt, CmdPktBytes);
  totalPackets++;
  uint8_t* ptr = (uint8_t*)&cmdpkt;

#ifdef TEST_MODE  
  Serial.println("debug rcv cmd:");
    // 打印索引行
  for (size_t j = 0; j < CmdPktBytes; ++j) {
    Serial.printf("%3d ", j);
  }
  Serial.println();

  // 打印数据行
  for (size_t j = 0; j < CmdPktBytes; ++j) {
    Serial.printf(" %02X ", ptr[j]);
  }
  Serial.println();
#endif
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

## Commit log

2026-06-13 Stage 01: leadscrew calibration sketch, procedure, and README
2026-06-13 Set DIR_AWAY_LEVEL to LOW (positive jog now moves away from sensor)
2026-06-13 Record leadscrew calibration results: 0.001 mm/pulse (2.0 mm/rev)
2026-06-13 Stage 02: add host logger + procedure; finalize sweep sketch
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2026-06-14 Stage 02: front end decided — div1.5, no cap (cap reproducibly adds noise); add data + figures
    [charac_div1p5_cap_retest_run1.csv, charac_div1p5_cap_run1.csv, charac_div1p5_nocap_retest_run1.csv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]
2026-06-14 Stage 02: eight-range characterization sweeps + family and sensitivity figures
    [charac_100mT_run1.csv, charac_12mT_run1.csv, charac_200mT_run1.csv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]
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2026-06-15 Stage 03: 100mT linearized + verified (2.6%); 200/400mT documented impractical
    [charac_100mT_linearized_run1.csv]
2026-06-15 Stage 03 complete: 6 ranges linearized + verified (1.4-3.1%); range ladder + findings
    [charac_12mT_linearized_run1.csv, charac_25mT_linearized_run1.csv, charac_3mT_linearized_run1.csv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]
2026-06-15 Stage 03: add before/after + coverage figures for review
2026-07-03 Handoff: two-board architecture, 3-sensor demo pin map, phased plan
2026-07-03 Linearize 3 peg sensors at 12mT (S1/S2/S3); per-sensor mV->mm lines + verify data
    [charac_S1_12mT_linearized_run1.csv, charac_S2_12mT_linearized_run1.csv, charac_S3_12mT_linearized_run1.csv]
2026-07-04 Add Board B 3-sensor live gape readout (Phase 1)
2026-07-04 Add Board B readout; correct closed-peg claim in deployment_calibration (closed sits in low clamp, verified vs 12mT CSVs)
2026-07-04 Board B web dashboard: live oyster-shell gape gauges; WiFi creds via gitignored secrets.h
2026-07-05 Reorganize data: sim_test_data (3-sensor 12/25mT), range test runs (linearized/non-linearized), cap_test_run
    [charac_100mT_linearized_run1.csv, charac_100mT_run1.csv, charac_12mT_linearized_run1.csv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]
2026-07-05 Rename 'range test runs' to range_test_runs (remove spaces from path)
    [charac_100mT_linearized_run1.csv, charac_100mT_run1.csv, charac_12mT_linearized_run1.csv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]
2026-07-05 Board B 25mT + tare: true gape from closed baseline; update deployment_calibration
2026-07-05 Board B tare: auto-scale gauge to per-unit physical max (gmax); doc note
2026-07-05 Refresh README to 25mT+tare stage; add bench demo (GIF + release video)
2026-07-05 Add Board B procedure (04); trim repo-structure block from README
2026-07-05 Mark 04/05 as superseded (12mT reference) to prevent stale-calibration misflash
    [04_board_b_readout.ino, 05_board_b_dashboard.ino]
2026-07-26 03: add 'probe <mm>' — single-point read for batch offset capture
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2026-07-31 nano_logger: RTC bench test (step 1) + pinmap + test log
    - 01_rtc_test.ino: DS3231 read/increment, no-coin-cell design (time_valid
    flag, explicit set, direct millis() print)
    - pinmap.md: single-source pin map for the Nano logger
    - bench_test_log.md: step 1 PASS, design notes, millis() bug fix recorded
    [01_rtc_test.ino]
2026-07-31 nano_logger: SD card bench test (step 2) PASS
    - CardInfo verifies full SPI chain (CS/MOSI/MISO/SCK) + FAT32 card read
    - confirms SCK/D13 healthy on this board (closes ICSP/SCK concern)
    - RTC + SD coexist on same board (I2C + SPI, no conflict)
2026-07-31 nano_logger: sensor read bench test (step 3a) PASS
    - 3x HAL 2425 on A0/A1/A2, 5V native, no divider
    - noise floor 0-2 counts at rest (good effective resolution on internal ADC)
    - each channel tracks its own peg, no cross-talk
2026-07-31 nano_logger: add step 3a sensor test sketch (delay=1000 for eyeball test)
    - was missing from previous commit (empty folder, not tracked)
    - delay(1000)=1 Hz is intentional display rate for human test; deployment
    logger runs 10 Hz. Rationale documented in sketch header.
    [sensor_read_test.ino]
2026-07-31 nano_logger: full logger (step 3) PASS with movement captured
    - 03_nano_logger_bench.ino: 6ch @10Hz, RTC+SD, time_valid schema, no auto-set
    - verified vs LOG0002: peg movement on A2/s3 captured cleanly; s1/s2 independent
    - documented floating-pin ADC crosstalk (unwired A3/A6/A7 ghost last driven
    channel A2) — benign bench artifact, disappears when all 6 pins driven;
    also a field diagnostic for disconnected sensors
    - notes Serial-Monitor-resets-board -> per-run files behavior
    [03_nano_logger_bench.ino]
2026-08-01 nano_logger/deployment: D1 baseline power measurement (51 mA)
    - powered from E3631A bench supply into 5V pin, USB off, supply reads current
    - bench logger draws 51 mA flat-out -> ~2.5 days on a 3000 mAh cell
    - documents lifetime math; sets the target for sleep/gating stages
2026-08-01 nano_logger/deployment: D2 v1 (RTC-alarm sleep) result + supersede note
    - sleep mechanism worked but forced 1Hz (DS3231 alarm min = 1s) + had a
    multi-sample-per-wake bug; ~40mA floor dominated by parasitics
    - decision: switch to watchdog/timer-interrupt wake (100ms) for 10Hz + sleep,
    RTC for timestamps only (per supervisor)
    - verified legacy repo has no sleep code (millis busy-loop)
2026-08-04 Add sensor_check.html: drag-and-drop PASS/FAIL + trace plot for verify sweeps
2026-08-04 nano_logger/deployment: power analysis States 0-1 (baseline + CPU sleep)
    - State 0 bare board empty sketch: 21 mA (E3631A), 18.3 mA (DMM verify)
    - State 1 deep sleep: 10 mA steady
    - CPU active ~11 mA (matches datasheet); parasitic floor 10 mA
    - documents method (USB-off), no visible watchdog spike (wake too brief for display)
2026-08-04 power analysis States 2-4: RTC, SD, ungated sensors
    - State 2 +RTC: +4mA asleep, mostly module LED (strippable)
    - State 3 +SD: +2mA, no LED, efficient; write spikes noted for profiler stage
    - State 4 sensors ungated: ~7.5mA each (consistent over 4 sensors)
    - 6-sensor extrapolation ~61mA asleep; sensors = largest load (~45mA)
    - gating projected to cut sensor draw ~45mA -> ~1.4mA: the #1 win
2026-08-04 power analysis State 5: GPIO-gated sensors (39mA -> 16mA, 3 sensors)
    - gated_sensor_test.ino: power sensors ~3% duty, deep-sleep between
    - 3 sensors ungated 39mA -> gated 16mA; ~23mA reclaimed
    - 6-sensor projection ~61mA -> ~17mA (~44mA saved) = biggest single win
    - twitches to 20-24mA = sensor-on pulses, confirm gating active
    - validates professor's GPIO-gating architecture on the bench
2026-08-05 power analysis State 6: strip RTC module LED (-3mA), RTC still works
    - removed D1 green power LED on HW-084 DS3231 module: 14mA -> 11mA (asleep)
    - RTC verified working after strip (ticks, anchors on 's')
    - documented sneak/back-feed current artifacts (3mA/7mA) to ignore, plus the
    deployment lesson: gated-off parts must not be back-fed via signal pins
2026-08-05 power analysis State 7: strip Nano PWR LED (10mA -> 7mA)
    - removed onboard PWR LED, ~3mA (clone LED runs bright)
    - bare-board sleeping floor now 7mA; remaining = CH340 (~5mA) + regulator
    - 2 LEDs stripped total ~6mA reclaimed; CH340 is next (sacrificial)
2026-08-05 power analysis: add scannable summary tables at top of doc
    - build-up table (states 0-5) and strip-down table (strips 1-3c) at a glance
    - key findings, 6-sensor projection, deployment implication
    - detailed chronological notes preserved below the summary
2026-08-05 power analysis Strip #4: remove regulator (7mA -> 2mA, ~5mA reclaimed)
    - AMS1117 regulator was the biggest hidden parasitic (~5mA), not the CH340
    - bare-board sleeping floor now ~2mA (was 10mA)
    - full gated+stripped node projects ~6-7mA avg vs 51mA original (~8x)
    - resolves the 10mA-floor breakdown: LED 3 + regulator 5 + ATmega/passives 2
2026-08-05 power analysis FINAL: stripped+gated node = 6mA (from 51mA)
    - working reprogrammable board: bare 2mA -> +RTC 3 -> +SD 5 -> +3 gated sensors 6mA
    - 6-sensor projection ~7-8mA avg; ~7-8x improvement, USB preserved
    - documents the VDD/signal wiring swap that caused a false 25mA, now fixed
    - deployment config: strip LEDs+regulator, keep CH340, gate sensors per-pin
2026-08-05 power analysis: extend top summary table with regulator strip + final 6mA node
2026-08-05 power analysis: MEASURED 6-sensor gated node = 6mA (from 51mA, ~10x)
    - all 6 sensors gated on D4-D9, signal A0-A3/A6/A7: settles 6mA, spikes ~20mA
    - 6 gated sensors ~= 3 gated sensors (both 6mA); replaces the projection
    - notes uncaptured spikes for profiler-based battery estimate
    - notes Mac CH340 driver conflict resolved by using another PC to upload
2026-08-05 deployment firmware: Timer1 10Hz interrupt logger (verified) + tradeoff notes
    - nano_logger_deploy_10hz.ino: Timer1 100ms interrupt wakes CPU -> gate 6
    sensors, read, RTC timestamp, SD write, sleep (supervisor's architecture)
    - verified 10Hz from LOG0003 (2009 rows @100ms); time_valid works; 6 ch logged
    - power ~9mA at 10Hz (IDLE sleep) vs ~6mA at 8Hz (deep sleep) = cost of exact 10Hz
    - L LED draw negligible (measurement corrected estimate)
    - documents watchdog-can't-do-10Hz and the RTC drop decision (time, not power)
    [nano_logger_deploy_10hz.ino]
2026-08-12 DAQ6510 precision measurement: true avg current 8.40mA at 10Hz
    - Keithley DAQ6510, 100k readings/50min in series, saved to USB
    - true time-weighted mean 8.40mA (bimodal: 70% @7.34mA, 30% @10.87mA)
    - E3631A/eyeball underestimated (~7mA); DAQ caught the spike-weighted truth
    - battery: 3500mAh ~17 days; 3-cell pack ~52 days (meets month+ target)
    - raw CSV + waveform/distribution plot committed
2026-08-14 docs: DAQ6510 campaign + power-integrity investigation
    - run1 true mean 8.40mA (10Hz deploy sketch); 3-cell pack ~52 days
    - runs 2/3 faults traced to DAQ series path, NOT board/firmware/SD/inrush
    - E3631A-alone ran flawless (21.7k rows clean 10Hz) = board is solid
    - documented capacitor decoupling physics (why cap fixed the DAQ-path sag)
    - fault = bench measurement artifact, deployment (direct battery) unaffected
    - watch: sensor6 all-zero in one log, verify contact
